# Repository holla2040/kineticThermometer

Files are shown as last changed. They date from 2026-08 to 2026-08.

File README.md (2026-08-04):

# Kinetic Thermometer

**[Live demo →](https://holla2040.github.io/kineticThermometer/)** ·
**[Phone version →](https://holla2040.github.io/kineticThermometer/mobile.html)**

An outdoor garden sculpture that displays temperature: a linear actuator
(24″ retracted / 42″ extended, 18″ stroke) drives a bell crank into two
chained four-bar linkages, and the indicator — the second stage's coupler
point — crawls along the serpentine curve it traces. The temperature scale
is engraved along that curve, with equal temperature steps landing at
unequal spacing. Viewers are meant to puzzle over how it works.

The design simulator sweeping −20 to 110°F: actuator, bell crank, two four-bar linkages, and the temperature path traced by the stage-2 coupler point

One frame per degree, so the animation gives every degree equal *time* —
which is why the indicator crawls where the path is compressed and races
where it opens out. That unevenness is the mechanism, not the recording.

## Files

- `index.html` — the interactive design simulator, served live at
  <https://holla2040.github.io/kineticThermometer/> (GitHub Pages, straight
  off `main`, so a push updates it). Or just open the file in any browser.
  No dependencies, fully self-contained. Drag the mounts and joint pins to
  reshape the linkage, tune the scale range and actuator excursion, undo
  with Ctrl/Cmd+Z, pan by right-dragging, zoom with the mouse wheel, rotate
  the view in 10° steps, and save named designs in the browser. A dashed
  bounding box gives the piece's footprint in inches at the current view
  angle. Double-click recenters and resets zoom. Exports DXF for Fusion —
  see below.
- `mobile.html` — the same simulator, portrait-first for a phone, served at
  <https://holla2040.github.io/kineticThermometer/mobile.html>. A narrow
  touch screen opening the live demo lands here automatically; add
  `?desktop=1` to force the desktop page instead. The controls hide behind
  the pill at the bottom of the screen — tap or drag it to bring the sheet
  up, and collapsed it gives the whole screen to the drawing. **There are no
  geometry sliders**: every
  length and mount position is set by dragging its pin, with the values you
  are changing shown at the top of the screen. Pinch to zoom (also how you
  get fine control — at 12× a pixel is about a hundredth of an inch),
  double-tap to recenter, and use the ▶ ↶ ⌖ buttons in place of the
  keyboard. Turned sideways the sheet becomes a left drawer. Presets, saves
  and both DXF exports all work. See "Two files, one core" below.
- `tools/search_geometry.py` — the constrained random search that found
  the preset geometries. `python3 tools/search_geometry.py` (a few minutes).
- `tools/analyze_geometry.py` — measures a saved design against the
  fabrication constraints: assembly across the stroke, scale length, per-10°F
  step lengths, cusps and kinks, mount clearance, and the actuator-triangle
  ceiling. Feed it a `__ct.dump()` capture (see below).
- `tools/verify_export.py` — drives `index.html` headless and checks the
  whole UI and both DXF exports. Run it after changing `index.html`.
- `tools/verify_mobile.py` — the same for `mobile.html` on a 390×844 phone
  viewport: the sheet, touch hit radii, pinch, double-tap, the drag
  tooltip, control parity against the desktop, and the landscape drawer.
- `tools/sync_core.py` — keeps the two pages' shared half identical.
- `FABRICATION.md` — what a shop needs: the chosen geometry, the measured
  scale behaviour, the DXF layer reference, and the concerns to settle before
  anything is cut.
- `TODO.md` — open work, known concerns, and a list of things already tried
  and deliberately reverted.
- `CLAUDE.md` — full project context and history. If you work on this
  project with Claude Code, start it in this folder and it reads this
  automatically.
- `ik-demo.html` — unrelated earlier FABRIK inverse-kinematics demo.

## Dead center — the thing to understand before you build one

If you only read one section of this repository before committing metal to a
design of your own, make it this one. It is the difference between a sculpture
that tells the time of day in degrees and one that quietly lies to you.

You do not need any mechanism theory to follow it. Start with a bicycle.

### The bicycle pedal

A crank at dead center gets no turning force from a straight-down push: on the left the pedal is at the top of its circle and the push produces no rotation; on the right, a quarter turn later, the same push has full leverage

When the pedal is at the very top, your foot, the crank and the axle are in one
straight line. Push straight down as hard as you like — the crank does not turn.
Which way it eventually goes is decided by your other foot, or by the bike
rocking, not by how hard you pushed.

That position has a name: **dead center**. Any linkage can reach one, and this
sculpture has two places where it can happen.

### Why a linkage has the same problem

The joints this mechanism has to *solve* for are found the same way: by
crossing two circles. (The others come straight off the crank angle.)

Take pin **D**. It has to sit exactly `L5` away from point P, and exactly `L6`
away from the ground mount O6. Draw a circle of each radius and D is where they
cross.

Two circles cross at two points, so there are two valid ways to assemble the linkage — the simulator picks one branch and stays on it

Two circles normally cross at **two** points. Both are perfectly valid
assemblies — that is exactly what the "assembly branch" flips in the panel
switch between. The mechanism sits on one and stays there.

Now push the circles apart until they only just touch:

When the two circles are tangent the two solutions merge into one and the linkage is at dead center, with both links in a straight line

The two crossings have merged into one. The two links are in a straight line —
the pedal at the top of its circle. Push a hair further and the circles do not
touch at all: there is no solution, and the simulator simply stops drawing the
linkage. That is the red "can't assemble" warning.

### Where it can happen here

The drive chain from actuator through bell crank, B, C, P and D to the indicator Q, showing that only C and D are found by crossing circles

Motion runs one way along that chain, and only **C** and **D** are found by
crossing circles. They are the only two joints that can go dead. The actuator's
own triangle could in principle do the same, but the code already keeps a hard
0.5″ margin there, so it never gets close.

### The number that measures it: transmission angle

Transmission angle at a joint: 65 degrees is healthy, 22 degrees is getting tight, 4 degrees is effectively dead center

At each of those joints, measure the angle between the link arriving and the
link being driven. That is the **transmission angle**.

- **90°** — perfect. All of the push goes into moving the next link.
- **above ~40°** — normal engineering practice.
- **near 0°** — dead center. The links are in a line and the push goes nowhere.

It is not a matter of opinion or of guessing which link pushes which. The angle
is fixed by the triangle formed by the two link lengths and the distance between
their anchor points, and it hits zero at exactly the moment the two circles stop
crossing. Same event, two ways of describing it.

### How the presets measure up

Where each preset falls on the transmission-angle scale: the eleven search examples all sit in the red zone below 6 degrees, serpentine reaches 7.7 degrees and Grand Arc 33.9 degrees

Every preset in the dropdown, worst case across its whole temperature range.
The jump column is what one press of the ↑ key does — 0.1″ of actuator travel:

| preset | closest approach to dead center | worst jump per 0.1″ of actuator |
|---|--:|--:|
| the six `clean-*` | **40.0° – 50.1°** | **0.7″ – 1.9″** |
| Grand Arc | 33.9° | 0.5″ |
| the six `shape-*` | 6.9° – 25.3° | 0.4″ – 3.2″ |
| Serpentine | 7.7° | 2.3″ |
| `example-00` … `example-10` | **0.06° – 5.9°** | **4.6″ – 28.9″** |

The two hand-tuned designs clear the danger zone. **All eleven `example-*`
presets sit inside it** — which is why each is marked with a `*` in the menu.

That is not bad luck. Those eleven came out of a numerical search told to make
the scale as long as possible, and near dead center the indicator sweeps furthest
for the least input — so "make it long" and "ride the singularity" turn out to be
the same instruction. The search walked straight to the edge and sat on it. They
are wonderful to watch and a perfect illustration of what to check for.

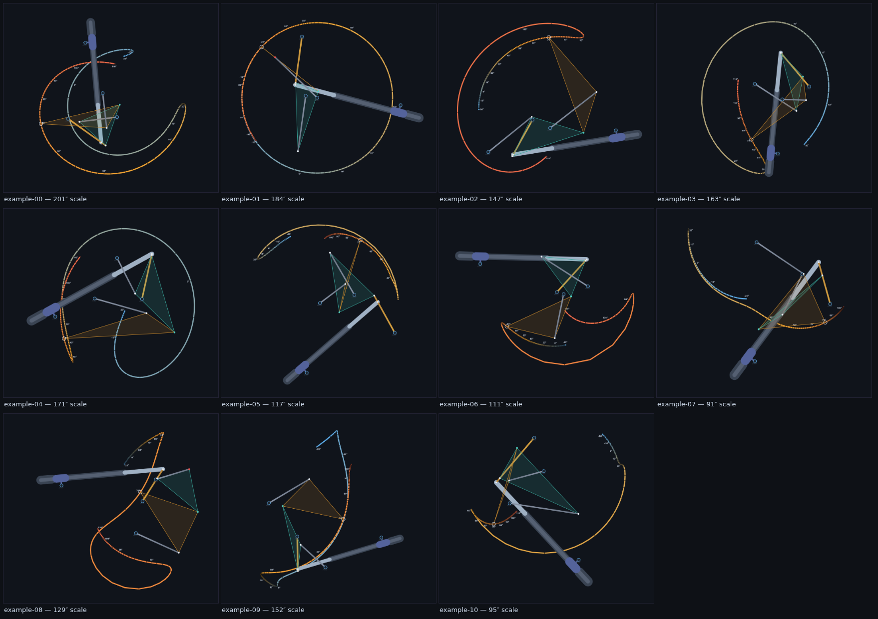
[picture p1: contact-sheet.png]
The eleven example presets, each showing the curve its indicator traces and the scale length in inches: spirals, loops, hooks and S-curves ranging from 91 to 201 inches


All eleven, as the dropdown draws them. Pick any one and watch it sweep — then
watch pins C and D. Regenerate this sheet with
`python3 tools/render_designs.py --presets contact-sheet.png`, which reads the
presets out of `index.html` rather than a saved file, so it cannot show a curve
the menu does not actually produce.

### The same search, told to stay away from the edge

The `clean-*` presets are the answer to the obvious follow-up question: if the
search only found those eleven because nothing stopped it, what does it find when
something does? `tools/explore_designs.py` now measures the transmission angle at
C and D exactly the way the page does, and `--tamin 40` refuses any design that
drops below the 40° figure this section recommends.

That first run produced ten, of which the owner kept three: the other seven were
variations on two shapes rather than seven designs. A second run then had to be
told what "a different shape" means — see "Asking for a shape you have not seen
yet" below — and produced the remaining three.

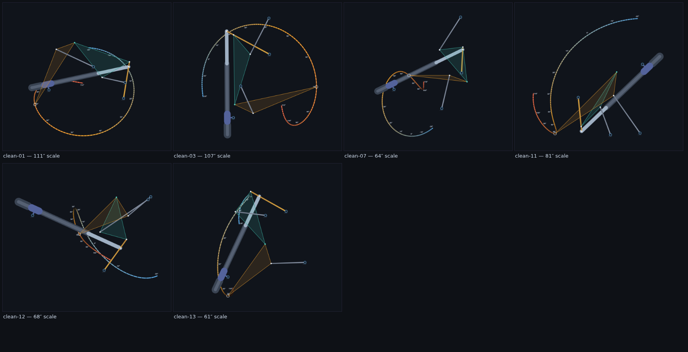
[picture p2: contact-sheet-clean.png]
The six clean presets, each showing the curve its indicator traces and the scale length in inches: open C-curves, nested arcs, an S and two self-crossing curves, from 61 to 111 inches


    python3 tools/explore_designs.py --tamin 40 --minlen 60 --trials 3000000
    python3 tools/render_designs.py --presets contact-sheet-clean.png /tmp/x clean-

Three things that run of the search settled, all of them worth knowing before you
draw a curve you like and then go looking for a linkage that traces it:

- **Healthy is common; healthy *and* long is not.** 94% of assemblable random
  geometries keep 10° or better. But in 2.4 million random trials, not one reached
  40° with even a 70″ scale. Every one of these ten had to be hill-climbed to.
- **A length-maximising search finds no loops above 40°, but they are there.**
  This is worth stating carefully, because the first run made it look like a law
  of the mechanism: every design it returned at 40° was an arc or an open spiral,
  and the obvious conclusion was that crossings and cusps simply *are* the
  singularity and cannot be had safely. That conclusion was wrong. Told to hunt
  for unfamiliar shapes instead of long ones, the same search returns curves that
  cross themselves once to three times at 40°–53°. What loops actually cost is
  even movement. Among the six kept, the two self-crossing designs sit at the
  bottom of the range at 0.074″ and 0.092″ per °F, while the loop-free ones reach
  0.50″ — though they overlap, since loop-free `clean-07` also stalls to 0.092″.
  That is a readability problem, not a branch-flip problem, and 0.075″ is what the
  owner's own serpentine manages.
- **You pay for it in scale length, and less than you would think.** The kept
  designs run 61″–111″ against the examples' 91″–201″, and get a linkage that
  cannot flip branch in a gust of wind.

They come out ahead on the fabrication rule too, which was not asked of them:
each keeps its mounts **2.89″–10.37″** off the engraved path, clearing the 2.5″
rule that the chosen serpentine misses at 2.06″. That is luck, not design — a
design far from dead center is not automatically buildable, and `clean-*` still
needs the rest of `analyze_geometry.py` run over it before anyone cuts metal.

### The same shapes, walked away from the edge

The `shape-*` presets answer a third question: not "what does the search find
when fenced off" but "can a shape chosen for its looks be moved to safety?"
Two provenances, one method — hold a target curve's shape while the search
climbs transmission angle:

- `shape-01` / `shape-02` hold the shapes of example-08 and example-00 at
  **13.1°** and **16.7°** — sixteen to twenty times the 0.8° margin those two
  seeds ride, at the cost of some scale length (88″ vs 129″, 138″ vs 201″ as
  shipped).
- `shape-03`…`shape-06` began as freehand drawings that never came from any
  linkage (`tools/propose_shapes.py`). An approximate-path-synthesis search
  (`explore_designs.py --targetpts --objective match`) found each drawing's
  closest mechanism curve, then climbed away from dead center holding that
  shape. The owner picked these four from a tagged sheet of every candidate;
  they land at **6.9°–25.3°**.

None reaches the 40° this section recommends, which is why the family is
named `shape-*` and not `clean-*`: how far from the singularity is far enough
is a judgment call, and every label carries its true minimum angle so nobody
has to re-derive it. The full frontier — what each increment of shape drift
buys in transmission angle, and which drawn shapes turned out to be
unreachable outright — is in `REPORT.md`.

### Asking for a shape you have not seen yet

Re-running the search with a new random seed does not give you a new shape. It
gives you another member of whichever family the objective favours, which is how
the first ten came back as two families wearing ten names. To get something
genuinely different the search has to be told what "different" means.

`--avoid designs.json --novelty N` does that. Each curve is reduced to its
**turning function** — how much it has turned, measured at ten equal-arc-length
stations, as turn per unit length. A circle is flat at 2π, a half circle flat at
π, an S changes sign, a spiral sits high. Position, rotation and size fall out by
construction, and mirroring the curve or running it backwards are folded out in
the comparison, so nothing scores as novel for being the same curve hung the
other way round. `--novelty` is then the distance, in radians, a design must keep
from every shape in the avoid file.

Two things about it are not adjustable to taste:

- **Ten stations, not twenty.** The resolution was calibrated against the owner's
  own grouping of the first ten designs into two families. At ten stations or
  fewer the closest cross-family pair is further apart than the widest
  within-family pair; by twelve that has inverted, because the measure has
  started describing local wiggle rather than overall shape.
- **It compares increments, not cumulative turning.** Running a cumulative
  profile backwards mixes its endpoint value into every difference, so it is not
  an isometry and the distance came out asymmetric — A was 1.9 from B while B was
  2.7 from A. On increments both symmetries are isometries and the distance is a
  metric. `--selfcheck` asserts it.

For scale: the two original families sit 6.3 apart at their closest. The designs
from the second run are at least 7.3 from every earlier shape, and at least 11.0
from *each other* — further apart, pairwise, than the two families they were told
to avoid.

### What goes wrong, part one: the scale becomes unreadable

Near dead center the one-degree scale marks bunch up and then a single degree jumps the whole width of the sculpture

The scale is engraved with a mark every degree. Near dead center the indicator
is moving enormously fast for a small actuator movement, so consecutive degrees
land far apart — while just before it, they pile on top of each other.

On one design the search found (kept out of the menu for this reason), a single
degree moved the indicator **39.7 inches** — over three feet of engraved curve
between two marks. Elsewhere on the same curve, the slowest degree moves it
**0.195 inches**. That is a 200:1 spread across one temperature scale.

### What goes wrong, part two: it can start reading the wrong temperature

This is the serious one.

After a snap-through the linkage settles on the mirror branch, putting the indicator somewhere different for the same actuator position

Remember that the two circles cross at two points, and the mechanism lives on
one of them. At dead center there is only one point — so nothing at all
determines which branch it comes off onto. Momentum, friction, a gust of wind,
gravity, or a few thousandths of slop in a pivot will decide.

If it comes off on the other branch, your sculpture is now assembled the mirror
way round. Nothing is bent. Nothing is broken. Nothing looks wrong. The
indicator is simply in a different place for the same temperature, and it stays
that way until something knocks it back through.

Outdoors, unattended, with wind and thermal cycling, that is not a hypothetical.

### What the simulator shows you

Three things, all live:

- **`*` in the preset menu** — this design passes within 6° of dead center
  somewhere in its range.
- **Pins C and D turn red** whenever their own transmission angle drops below
  6°. Run the sweep and watch: you will see exactly which joint, and at what
  temperature, the mechanism is in trouble.
- **The inner curve for that pin turns red too**, over the whole stretch of its
  travel that is inside the danger zone — so you can see the size of the problem
  with the animation paused. Turn on **Inner curves** in the Display section.

Load `example-05` and then `clean-08` and watch the difference: the first flashes
red at C and D and throws the ring across the piece, the second never colours at
all.

### If you are building one of these

1. **Watch the whole sweep before you cut anything.** Play the animation end to
   end with Inner curves on. If a pin flashes red, the design has a dead center
   in its working range.
2. **Aim for 40° minimum** transmission angle at both C and D. If you want a
   number to design to, that is the one.
3. **Treat anything under about 15° as a rebuild**, not a tweak. Dragging a
   handle a little will not fix it — the geometry wants to be there.
4. **A long scale is not automatically a good scale.** Length bought by
   approaching a singularity comes with both failure modes above. The chosen
   serpentine gives up length for a mechanism that behaves.
5. **Check the mount clearances separately.** Dead center is about the linkage;
   whether a mount lands on top of the engraved path is a different question, and
   `tools/analyze_geometry.py` reports it.
6. **Remember the simulator is frictionless and has no slop.** It will happily
   drive through a pose that real bearings, real wind loading and a real gearbox
   would jam, stall or snap through.

The eleven `example-*` presets are in the menu precisely so you can see all of
this happening in something real, rather than take it on trust — and the
`clean-*` ones so you can see what the same search produces when rule 2 is
enforced instead of hoped for.

## Exporting for CAD

Two buttons in the panel write ASCII DXF in inches:

- **Parts DXF** — the five fabricated links, each laid flat in its own local
  frame on its own layer, spaced out so they don't overlap. Outlines are
  sized by the pivot-hole and link-width fields.
- **Points DXF** — the assembly frame: the path, a division across it every
  degree, °F labels every 10°, the four mounts, and POINT entities to snap to.

Curves come out as line segments, not splines — fit a spline in Fusion if
you want one entity. The export carries the same 1° path divisions the
simulator draws, on layer `PATH_DIVISIONS`, so the engraving matches the
screen. Full layer reference in [FABRICATION.md](FABRICATION.md).

## Two files, one core

`index.html` and `mobile.html` are two hand-maintained pages that share one
solver, one DXF writer and one set of presets. That shared half — about 1050
of each file's ~1550 lines — sits between marker comments:

```
// ==== SHARED CORE START ====
// ==== SHARED CORE END ====
```

Edit the physics in `index.html`, then:

```
python3 tools/sync_core.py --apply     # copy it into mobile.html
python3 tools/sync_core.py             # --check: fail if they differ
```

Below the END marker each page keeps its own interaction layer — hit radii,
gestures, tooltips, resize — and that is deliberately different. Run the
`--check` after any change to either file; a silent drift between the two
would mean the phone and the desktop disagree about the geometry you cut.

## Handing a tuned design back

Drag the geometry until you like it, then in the browser console:

```js
copy(__ct.dump())
```

That copies geometry plus settings as JSON. Paste it into
`tools/analyze_geometry.py` to check it against the fabrication rules, or
hand it to Claude Code to make it the new preset.

## Continuing with Claude Code

```
cd kinetic-thermometer
claude
```

Then just describe what you want ("fix the O2 clearance", "add the
.linkage2 export") — CLAUDE.md gives it the design constraints, chosen
preset and code architecture; TODO.md gives it the open work.

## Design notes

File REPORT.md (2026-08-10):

# Seeded transmission-angle search — report (2026-08-03)

## The question, answered plainly

**Is the example-08 / example-00 shape reachable at a safe transmission angle?**

- **At 40° ("clean"): NO.** Neither seed's shape survives to 40°, in the
  original box or the widened one. Nothing here may be called clean, and
  nothing is named clean.
- **At 15–33°: YES.** The shape family holds together far above the README's
  15° "rebuild line". Recognisably-example-08 designs (shape distance ≤3)
  reach **25.4°**; loosening to same-family distance 4 reaches **32.9°** —
  within a degree of Grand Arc's 33.9°. Example-00's crescent reaches
  **20.8°** at distance 3 and **25.6°** at distance 5.

Example-08 itself sits at 0.8°. A2 (18.7°) is 23× further from dead center;
A7 (32.9°) is 41× further.

## The frontier (best dense-measured ta among finalists that held the shape)

| shape dist allowed | ex-08, orig box | ex-08, wide box | ex-00, orig box | ex-00, wide box |
|--:|--:|--:|--:|--:|
| 2 | 13.1° | **18.7°** | **16.7°** | 14.2° |
| 3 | 19.9° | **25.4°** | **20.8°** | 17.5° |
| 4 | **32.9°** | 28.3° | **21.8°** | 20.2° |
| 5 | 22.3° | **30.5°** | 24.6° | **25.6°** |

Distance scale: ~3 = recognisably the same design, ~5 = same family (the two
original clean families sit 6.3 apart). The non-monotone cells (ex-08 D=5
orig box) are hill-climb luck, not physics — the true frontier can only
improve as the allowance loosens.

The wide box (`--widebox`: cv2 ±32, cu2 0–34, L5 8–32; envelope cap still
48×48) helped example-08 at D=2/3/5 but was NOT the unlock it looked like it
would be — both seeds sat pinned at cv2=20, yet the best single point (32.9°)
came from the ORIGINAL box. Wide-box designs are marked on the sheet and are
not comparable to earlier runs.

## The 12 candidates (owner picks; suggested keep: five)

All: mount clearance ≥2.5″ ✓, stall ≥0.15″/°F ✓ (the search's min-segment
rule, not just the 0.07 floor), envelope ≤48×48 ✓, assembles over the full
16″ Joyce stroke ✓. None reach 40° — this family must NOT be named clean-*.

| | run | ta° | scale″ | loops | both | dens | stall | clear | envelope | d(ex08) | d(ex00) |
|--|--|--:|--:|--:|--:|--:|--:|--:|--|--:|--:|
| A1 | ta08b-d2 #1 | 13.1 | 92 | 1 | 4.09 | 1.66 | 0.154 | 5.5 | 37×42 | 2.0 | 13.6 |
| A2 | ta08w-d2 #1 | 18.7 | 86 | 1 | 4.09 | 1.56 | 0.150 | 3.8 | 35×43 | 2.0 | 14.5 |
| A3 | ta08b-d3 #1 | 19.9 | 67 | 1 | 3.79 | 1.11 | 0.150 | 6.6 | 45×41 | 3.0 | 14.1 |
| A4 | ta08w-d3 #1 | 25.4 | 96 | 1 | 3.77 | 1.49 | 0.150 | 7.2 | 45×46 | 3.0 | 14.3 |
| A5 | ta08w-d4 #1 | 28.3 | 89 | 1 | 3.65 | 1.45 | 0.150 | 11.5 | 42×45 | 3.7 | 14.9 |
| A6 | ta08w-d5 #1 | 30.5 | 95 | 1 | 3.76 | 1.53 | 0.150 | 11.9 | 44×44 | 4.7 | 13.8 |
| A7 | ta08b-d4 #1 | 32.9 | 62 | 1 | 3.57 | 1.10 | 0.150 | 6.6 | 38×43 | 4.0 | 14.5 |
| B1 | ta00-d2 #1 | 16.7 | 156 | 1 | 5.93 | 2.65 | 0.168 | 2.6 | 46×37 | 14.4 | 2.0 |
| B2 | ta00-d3 #1 | 20.8 | 134 | 1 | 5.36 | 2.29 | 0.152 | 2.5 | 45×38 | 14.3 | 3.0 |
| B3 | ta00-d4 #1 | 21.8 | 124 | 1 | 5.14 | 2.17 | 0.151 | 2.5 | 43×37 | 13.7 | 3.8 |
| B4 | ta00-d5 #1 | 24.6 | 88 | 1 | 4.31 | 1.54 | 0.150 | 2.5 | 44×37 | 14.6 | 5.0 |
| B5 | ta00w-d5 #1 | 25.6 | 93 | 2 | 4.26 | 1.61 | 0.151 | 2.5 | 46×35 | 14.3 | 5.0 |

Reference: example-08 is both 4.71 / dens 1.99 / stall 0.169; example-00 is
both 7.06 / dens 3.29 / stall 0.140. B1 is essentially example-00's wildness
(both 5.93, dens 2.65, 156″, stall 0.168) at 20× its distance from dead
center. Every candidate's nearest shipped preset is its own seed, margin ≥3
to anything else — no accidental clean-* lookalikes.

Wide-box entries (A2, A4, A5, A6, B5): found in the widened parameter box;
flagged because they are not comparable to original-box runs.

## Method (SEARCH-PLAN step 1 + 3)

- `--seedfrom` / `--target` / `--targetdist` / `--widebox` added to
  `tools/explore_designs.py`; `--selfcheck` extended and passing;
  `crosscheck_port.py` still matches the page to 1e-13.
- 600 jittered copies of the seed, hill-climbed 2400 iterations on
  `score_ta`: transmission angle, minus 150/rad of shape drift beyond the
  allowance, with stall and mount-clearance priced in. Sweep D = 2,3,4,5 ×
  two seeds × two boxes = 16 runs at `--nsamp 1041`.
- Step 4 of the plan (fresh gated random search) was NOT run: steps 1–3
  answered the question.
- **A measurement bug found and fixed on the way** (it predates this work):
  `measure()` decimated paths by array stride, silently dropping the curve's
  endpoint at some sample counts — at DENSE=1301 a hooked curve read up to
  5 rad from its own converged shape. Reference descriptors are now traced at
  2601 samples (where the descriptor converges), decimation keeps the
  endpoint, DENSE is 2601, and the selfcheck pins both. Consequence worth
  knowing: shape/novelty numbers previously computed at DENSE (e.g. in
  merge reports) wobbled by ~0.2 rad; the clean-1x novelty gating itself ran
  at 261 samples and is unaffected in substance.
- Coarse grids carry ~0.3–0.6 rad of corner-cutting shape bias (measured;
  canary assert added), which is why the climbs ran at `--nsamp 1041`.

## Outcome (updated 2026-08-03, later the same day)

The owner kept **A1 and B1 only** — shipped as presets **`shape-01`** (88″ as
shipped, 13° min) and **`shape-02`** (138″, 16° min) in both pages, verified —
and rejected the other ten as lookalikes of presets that already exist. The
remaining three designs will be found shape-FIRST: abstract proposal curves
(novelty ≥7.0 vs all 21 shipped shapes), owner picks from a contact sheet,
then approximate path synthesis reports how close the mechanism can get and
at what transmission angle. See TODO.md "New scale-curve designs".

Files: `candidates.png` (contact sheet), `candidates.json` (geometries +
metrics, labels A1–B5), `allrows.json` (all 128 finalists), seed/target JSONs
and all 16 run outputs, in the session scratchpad.

## Reverse pipeline calibration (2026-08-03, evening)

The shape-first pipeline (`tools/propose_shapes.py` →
`explore_designs.py --targetpts --objective match` → `--objective ta` lift)
was calibrated on four proposals before the owner's pick. See
`calibration.png` and `proposals.png`. What the numbers say:

- **A drawn wild shape is always matched AT dead center.** Best full-size
  matches: prop-05 dist 2.1 (visibly the drawing) at 0.8°; prop-12 dist 3.9
  at 0.2°; prop-01 dist 4.3 at 0.7°; prop-08 (wildest, 6.7 rad both ways)
  only reaches dist 6.1 — its wildness exceeds the mechanism's.
- **Lifting to safety is cheap at first, then steep, and shape-dependent.**
  prop-12: +0.1 rad of drift → 21.8°, +0.3 → 32.8°, +1.0 → 42.4°
  (clean-grade, but the lineage is gone by eye). prop-05: does not lift —
  8.4° at +2.0 rad is its ceiling; the meander IS a singular shape here.
- **Distance calibration by eye:** ~2 = the drawing; ~4 = clearly related
  (loop + ribbon survive); ~5+ = generic. The usable sweet spot for a
  drawn shape is dist ~4 at ~20-25° — inside the band the owner already
  accepted for shape-01/02.
- Two tool lessons, both fixed and selfchecked: `score_match` needs a length
  floor (the scale-free descriptor otherwise converges on 20″ midgets), and
  drawn-vs-traced descriptors carry a ~0.5 rad parametrization bias
  (arc-uniform vs stroke-uniform vertices; documented in `polyline_desc`).

Awaiting the owner's proposal picks; per pick the deliverable is this same
frontier — closest match plus lifted versions — judged by eye.

## Verdict on the owner's picks: props 4, 8, 9, 11, 15 (2026-08-03, night)

Full ladder in `verdict.png`. Two match rounds (2 seed pools + a refinement
climb) and 15 lift runs per the calibration protocol:

| pick | closest match | lift behaviour |
|---|---|---|
| prop-15 | **2.6** (the drawing, 91″) at 0.1° | does not lift: 2.3° at +1, 7.5° at generic |
| prop-09 | 3.1 (related, 80″) at 1.0° | does not lift: 9.0° at generic |
| prop-04 | 4.8 (loose) at 0.1° | lifts 11.8° → 23.8°, but rungs read generic |
| prop-08 | 5.2 — wilder than the mechanism | (lifts only because already generic) |
| prop-11 | 11.7 — **out of reach**, no such curve family | — |

Plain statement: **none of the five picked drawings is wearable at ≥13° while
still recognisable.** The two proposals with a usable pocket — prop-05 (the
drawing at 0.8°) and prop-12 (clearly related at 21.8°) — were not picked.

## Final outcome (2026-08-03, late)

A process failure surfaced here, worth recording: the owner expected every
design presented to be BUILDABLE, and the ladders above presented trade-offs
instead. Recovery: `verdict.png` was relabelled — every design numbered
(#1–#16) and tagged BUILDABLE / NOT at the 15° line, with the owner's actual
criterion clarified as **6°** (consistent with the serpentine's own 7.7°).
From that tagged sheet the owner chose tiles **#4, #7, #11, #14**, shipped as:

| preset | tile | ta° | scale″ (0–15.5″) | from drawing |
|---|---|--:|--:|---|
| shape-03 | #4 | 7.5 | 71 | prop-15, dist 5.0 |
| shape-04 | #7 | 6.9 | 43 | prop-09, dist 4.1 |
| shape-05 | #11 | 14.0 | 35 | prop-04, dist 5.1 |
| shape-06 | #14 | 25.3 | 36 | prop-08, dist 5.5 |

All four verifiers green; §13 pins each shape preset's angle to its label
value. The shape family is complete at six per the owner. Lesson applied
going forward: designs are presented ONLY with explicit numbered tiles and
buildable/not tags at the owner's stated criterion.

# Benchtop 3D-print model + native Fusion rebuild (branch `3dfab-level`, 2026-08-09)

Two pieces of work, in order: a generator that turns the flat serpentine into a
printable 3D model, and a hand transcription of that model into Fusion 360 as
jointed components so the thing actually articulates on screen.

## 1. The print pipeline (`tools/print3d.py`, `print/`) — commit ec9ee4e

The flat mechanism is lifted into 3D: a back plate carries posts of differing
lengths at the four fixed mounts, every moving link rides its own plane parallel
to the plate, and sleeves couple the joints across planes. The actuator is
replaced by a hand drive — a bar pivoting on the anchor post with a slot along
its axis, and a shuttle puck that rides the slot and pins to the crank's R hole.
That reproduces the actuator constraint exactly: R stays on the anchor line the
way `lenOf()` puts it, and **the slot ends ARE the stops at ext 0 and 15.5″**, so
the model cannot be pushed past the dA+rA ceiling.

Scale **5 mm per real inch** (1:5.1), chosen by `pick_scale` as the largest tidy
0.1 step that fits plate + margin on a 210 mm bed. Back plate 186 × 164 mm, bar
210 mm — everything prints flat, no supports.

**The level assignment is searched, not chosen.** `assign_levels` enumerates
every stacking of the six links and rejects any that collides at any of the 141
poses (same sampling as the page's `rangeValid`), where "collides" covers link
vs link, post shaft crossing a link's plane, sleeve crossing a link's plane, and
sleeve/post passing through the air band a puck or ring stub occupies. Survivors
are ranked by fewest levels, then least post+sleeve metal. The winner:

| level | 0 | 1 | 2 | 3 | 4 | 5 |
|---|---|---|---|---|---|---|
| part | rocker1 | plate1 | crank | bar | rocker2 | plate2 |

Pitch 12 mm (4 link + 8 air). `verify_hardware` then clears what the level
search does not: post shafts, sleeves, the puck, the ring and every nut/head
protrusion, checked pairwise per pose wherever two share an air band.

Four results here are load-bearing and must not be "improved":

- **The plates are hollow triangles**, not filled hulls. A filled plate2 sweeps
  over the O2 post at some pose and then *no* collision-free stacking exists at
  all. Hollow rings sweep far less and print just as flat.
- **The bar tip is trimmed** to `lmax + 0.1`. A longer tip collided with the P
  sleeve (7.1 mm centre distance against 10.75 needed). The outline's own end cap
  forms the stop wall.
- **B and R take flush heads in pockets** in the laminated crank, B from above
  and R from below. They sit only |rA−L2| = 6.2 mm apart on the crank arm, so a
  head beside the neighbouring joint's sleeve does not fit. `screw_table`
  asserts the orientation policy (`plate1 < crank < bar`) that makes this valid.
- **Level order**, as above.

Outputs: 16 STLs plus `assembly.stl` (everything placed at mid-stroke),
`PRINT.md` (BOM, screw/washer table, assembly order) and `fusion-data.json`
(exact mm coordinates, level table, post/sleeve lengths, pose checkpoints).
`PROMPT.md` is the handover written so the Fusion rebuild could happen on
another machine.

## 2. Native Fusion 360 assembly (2026-08-09)

Design **`kineticThermometer-bench-3dfab`** in project *solohm*, units mm, built
through the Fusion MCP link by transcribing `print/fusion-data.json`. Nothing
was re-derived; the owner's existing designs were not touched.

**15 components, 18 occurrences** — back plate (with feet, mount holes and the
raised scale ridge), the five links, bar, shuttle, ring, four posts, and sleeves
(8 mm ×4, 44 mm ×1). All flat extrusions on XY. Every hole landed within
**0.0016 mm** of its published mid-stroke world position; the residual is the
3-decimal rounding in the JSON, nothing else.

**20 as-built joints** (as-built, so creating them moved nothing): back plate
grounded; 10 rigid — four posts to the plate, five sleeves to the link they
stand on, ring to plate2 at Q; nine revolutes at O2, O4, O6, ANCH, B, C, P, D, R;
and one pin-slot, shuttle to bar, sliding on the bar's own X axis with limits at
the slot ends (−38.7498 / +38.7502 mm about mid = 120 … 197.5 from ANCH).

### Verification (all three asked for, all pass)

1. **Articulation stop to stop** — smooth, no popped joints, stops at both slot
   ends.
2. **Checkpoints** — R, B, C, P, D and Q at ext0 / mid / ext15.5 against
   `pose_checkpoints`: **worst error 0.0019 mm** (tolerance was 0.1). Q reads
   (−6.908, 110.455), (70.625, 129.587), (4.971, 99.500).
3. **Interference** at all three poses, coincident faces ignored: **zero pairs**
   — re-run after the scale ridge was added, still zero.

### Findings worth not re-deriving

- **A slider joint shuttle↔bar silently locks Fusion's solver; a pin-slot does
  not.** The joint is created without error and then joint values simply refuse
  to stick. Bisected by suppression: both four-bar loops drive correctly on
  their own, and the freeze appears only when the slider is added on top of the
  revolute at R. `PROMPT.md` predicted this and named pin-slot as the robust
  choice; it is not optional, it is the only one that works.
- **Consequence: the assembly has 2 DOF, not 1.** A pin-slot leaves the shuttle
  free to spin about its own screw — which a round boss on a round screw
  genuinely is. Only one DOF moves the mechanism. Making shuttle↔crank *rigid*
  instead would give exactly 1 and is kinematically identical; it was not done
  because `PROMPT.md` specifies a revolute there.
- **Drive in small steps or the second loop flips branch.** One large jump sends
  plate2/rocker2 to the other assembly solution (both are valid: |D−O6| = 70.000
  and |D−P| = 29.500 either way) and it does not come back on its own. Stepping
  at 0.4 mm tracks perfectly across the whole stroke. Dragging in the UI is
  continuous so a human will not hit this, but any script that drives this model
  must step. `Design.snapshots.revertPendingSnapshot()` restores the as-built
  pose; there is no `revert()`.
- **The scale ridge is a union of 140 capsules, not a sweep or loft.** The Q path
  self-crosses once, so a swept 1.2 × 1.2 profile fails there. Drawing the 140
  capsules into one sketch yields 417 profiles (0.2 s) which extrude and join to
  the plate in 6.6 s — the same construction `plate_mesh` uses, and it matches.
- **Fusion API notes** that cost time: `ExtrudeFeatureInput.participantBodies`
  wants a Python list, not an `ObjectCollection`; the root component's name
  cannot be set (it follows the document); a Join whose profile touches nothing
  makes a second body regardless of the operation, so order joins so each one
  touches (the ring had to be built hub → spokes → band); an annulus profile is
  the one with `profileLoops.count == 2`.

### Two measurements the model surfaced

- **`print3d.py`'s `GEO` is not the serpentine written up in CLAUDE.md.** Its
  2026-08-08 `__ct.dump()` traces **82.4″ of scale** over ext 0–15.5; CLAUDE.md's
  recorded serpentine numbers trace exactly **58.0″**, matching that document.
  Both were computed with the same solver. So the printed model — and now the
  Fusion model — is of a later tuning than the preset section describes. Nothing
  was changed; flagging it because the two documents currently disagree.
- **Parts swing off the plate edge over part of the stroke.** The plate is sized
  from the Q path + mounts + margin only, so nothing bounds where the other
  joints go. Joint centre plus link half-width, past the plate edge, over all
  141 poses:

  | joint | edge | past by | at ext |
  |---|---|--:|--:|
  | P | x+ | 31.27 mm | 9.30″ |
  | R | y− | 4.38 mm | 15.50″ |
  | D | x+ | 2.28 mm | 8.19″ |
  | B | y− | 1.96 mm | 15.50″ |

  The P overhang carries the 44 mm sleeve, so that column is cantilevered in
  mid-air for a stretch of the stroke. Not a collision and not a transcription
  error — it is what the generator produces — but it is the one thing a viewer
  will notice, and widening `plate_2d` to bound the joint traces (as
  `buildBBox` already does on the page) would fix it. **Unresolved; owner's
  call.** By contrast the ring's outer edge exactly reaches the plate's top edge
  at mid-stroke (0.000 mm), which is `MARGIN + POST_OD/2 = RING_OUT` by
  construction.

### Method note

`numpy`/`shapely`/`trimesh` are not installed on this machine, so the 141-point
Q path needed for the ridge could not come from `print3d.py`. Rather than
install, `pose()` was reimplemented in pure Python from CLAUDE.md's description
and **validated against all 18 published checkpoint values to 0.6 µm** before
use. Verification throughout was by driving the live Fusion document and reading
occurrence transforms back, the same pattern as the page's headless tests.

# Full-scale sculpture in Fusion, and the export pipeline (2026-08-09, later)

The owner asked for the round trip: pick a design in the web tool, hand it over,
get it built in Fusion. shape-01 was the example. What that exposed, in order.

## The pipeline: `export_trace.py` -> `benchmodel.py`

`print3d.py` accepts a `dump.json` (geo+cfg) already, so the page's `__ct.dump()`
is the natural handover. It is not sufficient on its own:

- **`print3d.py` builds the wrong mechanism for a joyce design.** `solve()` hard-codes
  `L = GEN_LMIN + linspace(0, GEN_EXTMAX)` — the generic 24..39.5″ drive length —
  rather than calling `drive_lengths()`. shape-01 is `actT:1` and runs
  23.351..38.803″. Different drive lengths, different crank angles, different curve.
  serpentine happens to be generic, which is why this never showed.

`tools/export_trace.py` therefore exports a **trace**: geo, cfg, and the joint
positions the PAGE computed at 141 poses, plus `lenOf`/`stroke`. Downstream
transcribes instead of re-deriving, which is the project's rule everywhere else,
and is right for both actuator types by construction.

`tools/benchmodel.py` consumes a trace and re-implements print3d's level search,
fastener policy and hardware verification **with no dependencies at all** — every
collision test in print3d is between capsules and discs, so shapely's polygon ops
reduce to exact segment-distance algebra. It runs in 0.06 s against print3d's
shapely, and **reproduces `print/fusion-data.json` value-for-value** for
serpentine (all 15 keys, every nested number, the 141-pose search, the level
assignment, the screw table, the checkpoints). That regression is the reason to
trust it on designs print3d has never seen.

Two generalisations it adds, both forced by shape-01:

- **The flush-pocket policy is derived, not asserted.** print3d asserts
  `plate1 < crank < bar` and refuses otherwise. The direction is derivable: the
  crank pocket opens away from the mating part, and the shuttle rides the face of
  the bar away from the crank. serpentine still comes out byte-identical.
- **`--cad-only`** separates two verdicts that print3d conflates: whether a CAD
  assembly is collision-free (posts, sleeves, puck, ring) and whether the physical
  build is (those plus every nut and head stub). A design can pass one and fail
  the other, and shape-01 does exactly that.

## What the gallery actually supports at bench scale

All 25 presets through the pipeline. Only **4 build**: serpentine, example-10,
clean-13, shape-06. **4 more need the mirrored fastener policy**: clean-07,
clean-11, shape-01, shape-05. **17 have no collision-free stacking at all**, killed
overwhelmingly by *post-crosses-link* — a fixed post standing through a higher
link's swept area. The bench design was tuned around serpentine, which is unusually
compact; the gallery presets sweep near the bed limit.

Separately, **7 of 25 have B/R pivot holes that merge** — see the shape-01 note in
CLAUDE.md. At full size with 3/8″ pivots that drops to 3, but shape-01 is one of them.

## The Joyce rod end is metric, and it dictates the crank

Measured off the owner's model (the imperial figures in FABRICATION.md are
conversions): pin **Ø12.000**, tang eye **Ø34.000**, tang thickness **14.000**,
tang width **26.000**, rod **Ø35.000**, pin 51.000 ahead of the tube front,
tang→rod step **27.000**. All mm, all exact. Only the tube is imperial (50.80 =
2.000″). Consequences, recorded in CLAUDE.md's actuator block:

- The crank runs on **ONE side of the tang**, not straddling it. Straddling puts
  B's nut inside the tang's plane, where the Ø34 eye needs ≥25.3 mm of B/R spacing;
  single-sided moves that hardware out of the plane and 24 mm suffices.
- The crank arm swings to within **18.2°** of the rod axis, and the 14 mm tang necks
  down from a Ø35 rod, so a plate tucked just clear of the tang fouls the rod
  27–120 mm behind the pin. At 75 mm wide the rod overlaps the plate at **every one
  of 401 poses**, so a local scallop is not an option — the crank is offset clear
  of the rod instead (mid-plane 21 mm, later 23 mm for margin).
- Single-sided means the R pin is in **single shear with an offset load**.

## The full-scale assembly

Document **`kineticThermometer`** (1:1, mm) in *solohm*; the 1:5.08 printed model
was renamed **`kineticThermometer-scaled`**. The actuator is a SAT copy, not a
linked reference — `Occurrences.addByInsert` throws `InternalValidationError` for
every combination of arguments in this Fusion build. It is placed by its own two
pivots: clamp pivot onto ANCH to 0.001 mm, rod pin onto R to 0.13 mm (that residual
is the page's `aClamp` 23.23″ against the model's true 589.909 mm).

Links 45 mm wide × 3.175 mm. Width was checked and is nearly free: the valid
stacking is identical at 45, 30 and 20 mm, and width does not affect the rod
clearance either, because the rod passes within 8.4 mm of the crank's own axis
where it leaves the tang.

**Z-stack straddles the actuator** — the only arrangement that works, since four of
the five links sweep across it:

| rocker1 | ACTUATOR | crank | plate1 | rocker2 | plate2 |
|--:|--:|--:|--:|--:|--:|
| −23 | 0 | +23 | +43 | +63 | +83 |

Clearances: rocker1 and crank 3.9 mm (pure z), plate1 21.9, rocker2 58.7, plate2 61.9.
The C column spans 59 mm straight through z = 0 and clears by **120 mm** — C never
comes within 148 mm of the actuator axis in plane.

- **plate1** is a closed triangle (all three of B, C, P are load paths); **plate2** is
  a **V at P**, 42% lighter, because Q carries only the indicator and is a pointer.
- The **indicator ring is integral to plate2's arm** — ID 70 / OD 100, no hub, no
  spokes, nothing bolted on. The arm ends in an eye you read through.
- The **scale is its own part**, a 12 × 6 bar on the coupler curve at z 72–78,
  3.41 mm under plate2's underside. 2047 mm long, 15.7 mm per °F average.
- The backplate was **deleted** — 968 × 937 × 6 mm was 43.8 kg and a solid wind sail,
  and the actuator's motor pod and clamp buried themselves in it (26,871 and
  5,094 mm³). A branching **frame** replaces it: flat, 8 mm, z −58..−50, front face
  25.4 mm behind rocker1 so it clears every link in z by construction. Total steel
  fell 48.5 → 15.9 kg.

## Things that cost time, recorded so they don't again

- **The scale can only be supported at 22 of 71 stations.** The first check said none:
  the scale IS the locus of Q, so plate2's arm sweeps over all of it. The escape is
  that a support post tops out at z = 72, below plate2's plane, so only the four
  lower links constrain it. The two clearest stations are 336 mm and 263 mm from any
  moving part.
- **plate1's P column pinches the scale** at one spot near 68 °F — 5.7 mm from the
  centreline, in 2 poses of 141. Any scale behind plate2 is crossed by plate2's own
  support column somewhere. Left unfixed at the owner's call; a small lateral kink in
  the bar costs nothing in reading accuracy, since the ring's centre is what reads.
- **Extruding every profile of a capsule-chain sketch fills the region the curve
  encloses.** The scale ridge came out 380,000 mm³ against a predicted 147,000 until
  the one 39,135 mm² island profile was filtered out by area. `print3d.py`'s STL
  ridge has the same shape of bug at much smaller scale.
- **`Occurrence.transform` and `transform2` both fail SILENTLY** for occurrences built
  with baked transforms in a parametric design. Rotating the assembly appeared to
  work and did nothing; the frame and posts moved and the mechanism did not. It was
  caught only because the interference check reported three pairs a rigid rotation
  cannot create. Rebuild at the new coordinates instead of trying to move.
- **The mounting orientation is `cfg.rot`, and it is not decoration.** The owner's is
  **170°** for shape-01. The model was first built at rot=0, which put the trunk
  180° out. Correct by rotating the design +170° about Z; verified by reading screen
  coordinates off the page at rot=170 and solving from two independent mount pairs,
  both giving +170.00°. **Ask for `cfg.rot` before deciding which way is up.**

# Making the full-scale assembly articulate (2026-08-09, late)

`kineticThermometer` now has **29 joints and drives**: push the actuator and the
whole mechanism follows, with the rod staying in its tube. Verified numerically —
`|R−ANCH|` matches `√((aClamp+e)² + off²)` to **0.0001 mm** across the entire
393.7 mm stroke, and the indicator Q lands on its expected point to **0.230 mm
median / 1.116 mm worst** over all 141 sample extensions.

## The actuator is a LINKED reference now, not a copy

The earlier SAT import was the root of a whole afternoon of wasted work. SAT is a
dumb solid format: it flattened the owner's three components into five loose bodies
in one component and **discarded the joints entirely**. Everything after that was
rebuilding, badly, something the source already had.

`Occurrences.addByInsert` had thrown `InternalValidationError` for every argument
combination, which is why the copy existed at all. **A Fusion update on 2026-08-09
fixed it** — on build 2705.0.87 both `isReferencedComponent=True` and `False`
succeed. Re-test it rather than assuming; the workaround is far worse than the
feature.

The owner's `Joyce QS11940 Linear Actuator` already contained `Slider 2` — rod↔tube,
Z axis, limits spanning exactly 406.4 mm = 16.0000″, the true stroke. Two things
were added to it (now **v11**): components renamed `Component1`→`tube`,
`Component2`→`rod`, and a **`clamp_slide`** slider so the clamp travels the tube over
`aClamp` 3.48″–24.66″, matching the drag handle the web tool exposes.

## aClamp is a design parameter and the insert must drive it

The clamp position is not fixed — the browser lets the user slide it, and `geo`
carries it (`aClamp`, 23.23″ for shape-01). `export_trace.py` already exported it;
what was missing was using it. The insert now:

1. computes the clamp pivot's local position for the exported `aClamp`
   (`z = 51 − aClamp_mm`, lateral offset 60.404),
2. builds the placement matrix from THAT, so clamp pivot → ANCH and rod pin → R,
3. drives `clamp_slide` to match, then **captures a position snapshot**,
4. only then creates the joints.

Skipping step 3 left a **0.133 mm** residual — exactly `aClamp` 23.23″ against the
model's as-drawn 23.2247″ — which had been visible for hours as an unexplained
rod-pin error and dismissed as rounding. It was not rounding.

## The clamp lock: host-side, and order-dependent

The clamp must be free in the source but fixed once installed. Locking it in the
source is wrong — it destroys the adjustability the part actually has.

The working recipe, and it is fussy:

- suppress `clamp_slide` **in the host assembly context** (`createForAssemblyContext`
  → `isSuppressed = True`), then create a host rigid joint `lock_clamp_to_tube`
  between the linked children — **both in the SAME script run**.
- The host-context suppression **does not survive between script runs**; read back in
  a later call it reports `False`. But the rigid joint, once created that way,
  persists through save and reload with `isSuppressed = False`.
- Attempting the two steps in separate runs always fails: the create is rejected as
  "a joint in system exists", and un-suppressing the lock while `clamp_slide` is live
  gets it auto-suppressed again on the next rebuild.

## A diagnosis worth remembering

With the clamp unlocked, driving the actuator produced `|R−ANCH|` **exactly** constant
at 593.126 mm. That was read as "the solver refuses, the loop is over-constrained".
It was the opposite: the loop was UNDER-constrained and `clamp_slide` was absorbing
the entire input — the rod extended by *e* relative to the tube while the tube slid
back through the clamp by the same *e*, so R never moved. **A perfectly constant
output under a varying input means absorption, not refusal.** The owner spotted this
from watching the model; three API-side hypotheses had missed it.

## Fusion API notes that cost real time

- **`JointDirections` resolve against the JOINT GEOMETRY's frame**, not the
  component's. Handing a slider the clamp's pin hole made it slide along the pin
  axis. Pick geometry whose normal IS the wanted direction — a circle edge on the
  tube gives the tube axis.
- **`CustomJointDirection` is ignored by `AsBuiltJointInput`.** Native construction
  axis, assembly-context proxy, cylindrical face and straight BRepEdge were all
  silently discarded (`customSlideDirectionEntity` reads `None`), falling back to
  world X for pin-slot and −Z for slider.
- **Driving a joint creates a pending position that later joint creation REVERTS**,
  undoing any placement done after it. `Design.snapshots.add()` captures it first.
- **`Document.save()` can return `True` and do nothing.** Verify by re-reading
  `dataFile.versionNumber` — and note `app.data.findFileById()` can return a stale
  cached DataFile, so `document.dataFile` is the more reliable read.
- **One file can be open twice with divergent in-memory contents**, one view showing
  the edits and the other the original. That state blocks saving. Close both and
  reopen a single clean view.
- **A reference update resets host-side overrides.** After
  `FusionDocument.updateAllReferences()` the sub-assembly joint came back
  unsuppressed and at its as-drawn position; the lock and the `aClamp` setting both
  had to be re-applied.

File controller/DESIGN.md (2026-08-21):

# Controller design — ongoing discussion

The electronics that drive the sculpture: temperature sensor → controller →
linear actuator position. The sim's temp→extension mapping (linear within the
excursion, optional reverse — see FABRICATION.md) is the spec this controller
must implement.

System bus: **12 V or 24 V** — the design must run on either. That choice
ripples through every section below (battery config, solar charge controller,
motor driver voltage ratings, buck regulator input range). *Note: the
off-the-shelf solar panel decision effectively pins this to 12 V — see
[Solar](#solar-interface-for-charging).*

Layout: `docs/` notes and datasheets, `src/firmware/`, `src/babysteps/`
(bring-up experiments), `src/web/`.

**Document rules (owner, 2026-08-20):** this file is the **single point of
truth** for the controller. Every research finding lands here — URLs, prices,
part numbers, measurements, decisions *and their rationale* — so no decision
ever gets rehashed and a future agent needs nothing from chat scrollback. If
research turns up a source, the source goes in this file.

**Provenance note:** a longer motor-driver selection conversation predates the
ChatGPT share linked in the Motor drivers section — the share opens mid-thread
("the parts we discussed"). Searched for on 2026-08-20 in this repo, this
project's session transcripts, and memory: not found. If the owner surfaces
the original thread, fold it in here.

---

## Contents

- [Decision summary](#decision-summary)
- [Hardware](#hardware)
  - [MCU](#mcu---decided-2026-08-20)
    - [Production board: ESP32-S3-WROOM module](#production-board-esp32-s3-wroom-module-on-the-controller-pcb---decided-2026-08-20)
      - [PCB reference: a WROOM board drawn end to end in KiCad](#pcb-reference-a-wroom-board-drawn-end-to-end-in-kicad--2026-08-21)
  - [Motor drivers (need 2)](#motor-drivers-need-2---decided-2026-08-20-ti-drv8245-q1)
  - [Temperature sensor](#temperature-sensor---decided-2026-08-20)
  - [Power supply](#power-supply---open)
  - [Battery and charger](#battery-and-charger---battery-decided-2026-08-20)
  - [Solar interface for charging](#solar-interface-for-charging)
  - [Enclosure](#enclosure---open)
- [Firmware](#firmware)
  - [Homing cycle and position feedback](#homing-cycle-and-position-feedback--required)
  - [Calibration](#calibration--required)
  - [Power management](#power-management)
  - [Dashboard](#dashboard)
  - [OTA updates](#ota-updates--required)
  - [Network / discovery](#network--discovery--required)
- [Features](#features)
  - [Walk-up forecast mode](#walk-up-forecast-mode---proposed-2026-08-20)

---

## Decision summary

Status markers used throughout: ✅ decided · 🔶 open · 💡 proposed

| Topic | Status | Decision |
|---|---|---|
| MCU, bring-up | ✅ 2026-08-20 | ESP32 DevKitC (owner has many) |
| MCU, production | ✅ 2026-08-20 | ESP32-S3-WROOM-1 module on the controller PCB |
| Battery | ✅ 2026-08-20 | 12 V 7 Ah UPS-style sealed AGM |
| Solar panel | ⏸ deferred 2026-08-20 | Retail trickle maintainer, **5 W tier** — see [Panel research round 2](#panel-research-round-2-2026-08-20); top pick on record: SUNER POWER BC-5W Pro. Load ≤2.5 Wh/day (WiFi always on), so 5 W is the smallest framed+weatherproof+float-regulated retail box, not a capacity need. Undersized → customer buys bigger |
| Temperature sensor | ✅ 2026-08-20 | TI TMP117 |
| Bus voltage | 🔶 | 12 V or 24 V required; retail panel choice pushes 12 V — confirm |
| Motor driver | ✅ 2026-08-20 | TI DRV8245-Q1 — quality over cost |
| Charge controller | 🔶 | Must float-regulate SLA; pick with the panel |
| Forecast provider | 🔶 | NWS/weather.gov leading (free, keyless, US-only) |
| Walk-up forecast mode + servo dial | 💡 | Proposed feature, spec'd below |

---

## Hardware

### MCU — ✅ decided 2026-08-20

**Bring-up: ESP32 DevKitC** — owner has plenty on hand. Board references in
`docs/`: DevKitC v4 schematic, DOIT-variant schematic, and two pinout images.

#### Production board: ESP32-S3-WROOM module on the controller PCB — ✅ decided 2026-08-20

Skip the daughter-card-and-header-pins arrangement entirely: solder an
**ESP32-S3-WROOM-1 module** down on the controller PCB itself. Owner's
verdict on module-vs-bare-chip: "a no-brainer" — the module carries flash,
RF matching and antenna built in, is FCC/CE **pre-certified** as an
intentional radiator (key for the for-sale version), and is stocked at
LCSC / assembled at JLC (table below). The bare-chip + own-PCB-antenna route
(cheaper BOM, but we'd own RF layout and radio certification) is **rejected**.

**LCSC/JLC availability (checked 2026-08-20): yes** — same pipeline as the
motor drivers:

| Variant | LCSC # | Notes |
|---|---|---|
| ESP32-S3-WROOM-1-N8 | C2913198 | 8 MB flash, ~$3.03, in stock |
| ESP32-S3-WROOM-1-N16 | C2913199 | 16 MB flash |
| ESP32-S3-WROOM-1-N8R8 | C2913201 | 8 MB flash + 8 MB PSRAM |
| ESP32-S3-WROOM-1-N16R8 | C2913202 | 16 MB flash + 8 MB PSRAM |
| ESP32-S3-WROOM-1U-N8 | C2980297 | U = external-antenna connector version |

The N8 covers this firmware easily (web UI + OTA needs dual app partitions —
8 MB is roomy; PSRAM is for camera/LLM-class loads we don't have). The 1U
variant is the escape hatch if the metal sculpture ends up shadowing the
on-module antenna.

S3 side benefits over the classic ESP32: native USB (no CP2102 bridge), and
none of the devkit's AMS1117/USB-bridge quiescent draw — the board can be
designed to actually reach the low-power numbers the Power-management
section wants.

Plan: **DevKitC for bring-up (`src/babysteps/`), integrated S3 board as the
production design.**

Sources (checked 2026-08-20):

- N8 at LCSC (~$3.03, in stock): <https://lcsc.com/product-detail/WiFi-Modules_Espressif-Systems-ESP32-S3-WROOM-1-N8_C2913198.html>
- N16R8 at LCSC: <https://www.lcsc.com/product-detail/WiFi-Modules_Espressif-Systems-ESP32-S3-WROOM-1-N16R8_C2913202.html>
- JLC assembly listing (N16R8 example): <https://jlcpcb.com/partdetail/3198300-ESP32_S3_WROOM_1N16R8/C2913202>
- Module datasheet: <https://www.espressif.com/sites/default/files/documentation/esp32-s3-wroom-1_wroom-1u_datasheet_en.pdf>
- Espressif hardware design guidelines (schematic/layout/antenna keep-out): <https://docs.espressif.com/projects/esp-hardware-design-guidelines/en/latest/esp32s3/>

#### PCB reference: a WROOM board drawn end to end in KiCad — 2026-08-21

Video reference for drawing this board: *"ESP32-S3 Simple TestBoard designed in
KiCad"*, **made by morten**, 2:29:31, uploaded 2026-08-21 —
<https://www.youtube.com/watch?v=Z5AQMZh3qXw>. An unbroken real-time build of an
ESP32-S3-WROOM-1 board: blank schematic → symbols → footprints → BOM →
45 × 45 mm 4-layer stackup → routing → copper zones → silkscreen → DRC →
Gerbers → fab upload. Machine-transcribed here 2026-08-21 (Whisper
`large-v3-turbo`); digested notes with a timestamp index in
[`docs/video-kicad-esp32s3-morten.md`](docs/video-kicad-esp32s3-morten.md), full
transcript in
[`docs/video-kicad-esp32s3-morten-transcript.md`](docs/video-kicad-esp32s3-morten-transcript.md).
His board is orderable at
<https://www.pcbway.com/project/shareproject/ESP32_S3_SIMPLE_TestBoard_b77edcef.html>.

The findings that touch decisions in this document:

- **PSRAM costs three GPIOs.** On `-R8` (octal-PSRAM) WROOM variants **IO35,
  IO36 and IO37 are used internally** and are unusable. We chose the N8, so they
  are ours — but the `1U`/R8 escape hatch above stops being free the moment
  firmware hard-codes them. Keep IO35–37 unassigned if it costs nothing.
- **Strapping pins**: GPIO0, GPIO3, GPIO45, GPIO46. We have pins to spare —
  don't use them. GPIO3 takes a 10 kΩ pull-up; GPIO0 + EN + RX/TX belong to the
  programming header.
- **EN/reset network**: button EN→GND, 10 kΩ pull-up, 1 µF EN→GND for the reset
  RC, **and an ESD diode on EN** because a finger reaches that button. That last
  part generalises: the walk-up forecast button below is a user-touched GPIO on
  an outdoor metal sculpture, so **every user-facing GPIO gets an ESD part**.
- **Decoupling**: 10 µF + 100 nF at the module, with the **100 nF closest to the
  module VCC pin** in layout.
- **Qwiic (JST SH 4-pin, SM04B-SRSS-TB) for the I²C sensor** — pin 1 GND, 2 VCC,
  3 SDA, 4 SCL; pull-ups **2.2 kΩ** (10 k was drawn and corrected); default S3
  I²C is IO8 SDA / IO9 SCL. 💡 This is the tidy way to put the **TMP117** on a
  cable, off the board and out of its self-heating — spec at
  <https://www.sparkfun.com/qwiic>. 🔶 Open: whether the sensor hangs on a Qwiic
  cable or gets its own sealed gland-and-terminal run, given the outdoor
  environment (JST SH is an indoor connector).
- **A 6-pin ESP-Prog programming header** (EN, TXD, RXD, 3V3, GND, IO0) is a
  complete substitute for on-board USB-UART. We picked the S3 partly *for*
  native USB, so this is not a replacement — but footprinting the header is
  cheap insurance if native-USB bring-up stalls.
- **4-layer stackup that suits us**: top signal / In1 **GND plane** / In2
  **3V3 plane** / bottom signal. Zone settings used: clearance 0.2 mm, thermal
  gap 0.2 mm, spoke 0.3 mm.
- **Workflow**: assign footprints in the *schematic* editor (Tools → Edit Symbol
  Fields), not the PCB editor, so the PCB can't silently substitute one; the same
  dialog carries custom BOM columns (distributor part numbers) and the
  exclude-from-BOM / DNP flags. Annotate before the final BOM export.

**Do not treat it as a template for the whole controller PCB.** It is a
milliamp signal board: linear LM1117 from 5 V (not our 12 V buck), 0.6 mm
"power" tracks, no motor drivers, no high-current copper or thermal work, no
return-path/plane splitting, no impedance control (skipped even on USB), and
nothing about surge, reverse-polarity or transient protection on field wiring.
Those are the hard parts of *our* layout and this video does not touch them.

---

### Motor drivers (need 2) — ✅ decided 2026-08-20: TI DRV8245-Q1

Two driver channels required. The shortlist below was compiled for one
channel at 3–5 A continuous; whatever is chosen, use two (or a dual-channel
part covering both).

**Current sensing is a hard requirement** (added 2026-08-20): the homing
cycle detects the actuator's internal end stops by the motor current
dropping to zero (see [Homing](#homing-cycle-and-position-feedback--required)).
The chosen driver must expose motor current to the ESP32 — the DRV8245's
integrated current-sense mirror fits this exactly; for others, check for a
current-sense pin or budget an external shunt.

**24 V check needed**: the shortlist was drawn up before the 12-or-24 V
requirement. DRV8245 (4.5–35 V) and MP6615 (4.75–40 V) cover a 24 V bus with
headroom; the VNH7070 is an automotive 12 V-class part — verify its max
supply rating before keeping it on a 24 V design. (Moot if the bus is pinned
to 12 V by the solar decision.)

#### Shortlist (from ChatGPT "Motor Driver Stock Watch", summarized 2026-08-20)

Source: <https://chatgpt.com/share/6a87cd95-d654-83e8-84fd-84b7e82c4eb0>

Goal: an integrated H-bridge, orderable through LCSC and assemblable at JLC.
LCSC exposes live price tiers; JLC only shows unit price during
BOM/pre-order, so all prices below are LCSC (USD, checked 2026-08-15).

| Part | LCSC # | Stock | 1 pc | 100 pcs | Verdict |
|---|---|---|---|---|---|
| TI DRV8245HQRXZRQ1 | C5218845 | 224 | $7.73 | $6.09 | Best overall choice |
| ST VNH7070ASTR | C2150622 | 2,209 | $3.93 | $2.74 | Best value / availability |
| Infineon IFX9201SG | C112633 | 427 | $4.30 | $2.77 | Reasonable, not first choice |
| NXP MC33926PNB | C1556870 | 43 | $8.14 | $6.34 | Expensive and old; avoid |
| MPS MP6615GQKT-Z | — | — | — | — | No LCSC listing at first check |
| MPS MP6612GF-Z | — | — | — | — | No LCSC listing |

Reasoning:

- **DRV8245** — best engineering choice: newest architecture, ~32 mΩ bridge
  resistance, 4.5–35 V, built-in current sensing/regulation, compact VQFN.
  Costs ~$3.35 more per unit than the VNH7070 at qty 100.
  Ratings clarified 2026-08-20 (owner asked "is it a 32 A device?"): yes —
  TI headlines it as a **40-V, 32-A peak** H-bridge; the identical "32" in
  mΩ and A is coincidence. At our 3–5 A continuous it has huge margin;
  32 A is peak/stall handling, continuous is thermally limited far above
  our operating point. Datasheet:
  <https://www.ti.com/lit/ds/symlink/drv8245-q1.pdf>
- **VNH7070** — best cost/availability: $2.74 @100, 2,200+ in stock,
  15 A-class integrated bridge, ~70 mΩ RDS(on).
- **IFX9201** — worth considering only if its SPI diagnostics appeal.
- **MC33926** — costs more than the DRV8245 with dramatically higher losses
  and a larger package; do not design in.

**Follow-up update** (same thread, later check): the **MP6615 is now in the
LCSC/JLC ecosystem** as **C22697501** — TQFN-26 6×6 mm, SMT Extended Library,
4.75–40 V, 8 A continuous, 11 mΩ per MOSFET, ~¥28.08 (≈$3.90). DRV8245 stock
improved to 248. That makes the MP6615 a real third contender it wasn't at
the first check.

#### Decision — ✅ TI DRV8245-Q1 (2026-08-20)

Owner: "a no-brainer. I'm not too concerned about the cost of the device.
I'm more concerned about the quality." The ~$3.35/unit premium over the
VNH7070 is accepted. Rationale:

- Newest part on the list: datasheet SLVSFJ1E dated **November 2021**
  (rev. June 2026), TI's current-generation DRV824x-Q1 automotive family.
  The ST VNH7070AS is a mid-2010s design (~2016); the NXP MC33926 is
  2008-era.
- **Datasheet-verified 2026-08-20** (PDF pulled and read, first 3 pages):
  I<sub>OUT</sub> max **32 A**, R<sub>ON</sub> **32 mΩ** in VQFN-HR-16 (the
  LCSC part's package; HTSSOP-28 variant is 40 mΩ/32 A), 4.5–35 V operating,
  40 V abs max, **integrated current sense with proportional IPROPI output**
  — exactly what the homing cycle's current-drop detection needs, no
  external shunt. Huge margin at our 3–5 A.
- LCSC C5218845, ~$6.09 @100 (2026-08-15 pricing above).

Note: the owner asked whether the TI part is newer than "the Toshiba part" —
**no Toshiba device was in this shortlist**; the nearest intended comparison
is the ST VNH7070. If a Toshiba TB67-series part was discussed, it was in
the unrecovered pre-share thread (see Provenance note).

The question this closed, kept for the record: *at 3–5 A continuous, does
the DRV8245's thermal advantage (~32 mΩ vs the VNH7070's ~70 mΩ) justify
~$3.35/unit? And does the MP6615's 11 mΩ/FET at ~$3.90 undercut both?*
Answer: moot — cost was dropped as a criterion; quality/newness decided it.
The full shortlist, per-part reasoning, prices, and the MP6615 follow-up
remain above; the VNH7070 (best value) and MP6615 (best mΩ/$) stay recorded
as the fallbacks if the DRV8245's supply ever dries up.

Part references:

- TI DRV8245-Q1 product page: <https://www.ti.com/product/DRV8245-Q1>
- ST VNH7070AS product page: <https://www.st.com/en/automotive-analog-and-power/vnh7070as.html>
- MPS MP6615: <https://www.monolithicpower.com/> (search MP6615)
- LCSC part pages resolve from the C-numbers in the table, e.g.
  <https://www.lcsc.com/search?q=C5218845>

---

### Temperature sensor — ✅ decided 2026-08-20

**TI TMP117** — I²C, 1.8–5.5 V supply, wired to the ESP32's I²C. Accuracy
**±0.1 °C over −20 to +50 °C** — owner reviewed that figure and accepted it
as sufficient for this sculpture (2026-08-20). Product page / datasheet:
<https://www.ti.com/product/TMP117>

🔶 Open: outdoor placement/housing (radiation shield, cable run) so it reads
air temperature, not enclosure temperature — and outside the electronics
enclosure's self-heating (see [Enclosure](#enclosure)).

---

### Power supply — 🔶 open

Battery bus (12 V or 24 V) → logic rails for the ESP32 and sensors.

- Needs a wide-input buck covering both buses (roughly 9–30 V in) → 5 V for
  the DevKitC's VIN, which regulates 3.3 V on-board.
- 🔶 Open: part selection, quiescent draw (this runs 24/7 outdoors — idle
  current matters more than peak), reverse-polarity and surge protection at
  the battery input.

---

### Battery and charger — ✅ battery decided 2026-08-20

**Lead-acid, UPS-style:** the standard 12 V 7 Ah sealed AGM brick
(CSB GP1272 / Power-Sonic PS-1270 / Yuasa NP7-12 — interchangeable,
~$20–30). Case 151 × 65 × 94 mm, F2 faston terminals preferred. Charges fine
below freezing, unlike LiFePO4 — right for a −20 °F outdoor piece.
One battery = 12 V bus; two in series = 24 V (exactly how 24 V UPSes are
built). Float 13.6–13.8 V, cycle 14.4–14.7 V per battery.

- 🔶 Open: capacity check — is 7 Ah enough for actuator duty cycle + ESP32
  idle draw through winter nights? Same case family goes to 9 Ah (e.g.
  PS-1290) if not.
- 🔶 Open: charger — likely combined with the solar charge controller rather
  than a separate unit.

Sources (checked 2026-08-20):

- CSB GP1272F2 (the APC OEM cell): <https://www.amazon.com/CSB-GP1272F2-Volt-Sealed-Battery/dp/B00HKJ1FW6>
  and <https://www.osibatteries.com/csb-gp1272f2-battery-12v-7-2ah-sealed-lead-acid>
- Power-Sonic PS-1270F1 at Home Depot: <https://www.homedepot.com/p/12-Volt-7-Ah-F1-Terminal-Sealed-Lead-Acid-SLA-Rechargeable-Battery-PS-1270F1/312948092>
- Yuasa NP7-12: <https://www.amazon.com/Yuasa-NP7-12-Sealed-Battery-Terminal/dp/B00FA61Q1G>

---

### Solar interface for charging

> **Read [Panel research round 2](#panel-research-round-2-2026-08-20) at the
> end of this section first.** The load was restated on 2026-08-20 (ESP32
> duty-cycled, 1 s awake per 30 s → ~0.5 Wh/day), which supersedes the 10 W
> recommendation below and re-targets the panel to the **5 W** tier.
> Everything between here and there is kept as the record of how the earlier
> number was reached, and the round-1 candidate list did not survive re-check.

**STATUS 2026-08-20: panel decision DEFERRED (owner).** Assume some
5–10 W retail trickle charger that is suitable, easily available, and
replaceable; pick the exact model later. If a customer's panel proves too
small for their site, they buy a bigger one — that's the virtue of the
off-the-shelf decision. The power analysis in Firmware → Power management
puts the load at ≤2.5 Wh/day with WiFi always on, so any 5–10 W maintainer
has multiples of margin. Everything below (budget history, sizing math,
candidates, remote placement, cautions) stands as research for that later
pick — none of it blocks the rest of the design.

#### Energy budget (researched 2026-08-20)

Operating scheme (owner): firmware polls the TMP117 continuously and moves
the motor only on a **≥1° change** — short ~1 A @ 12 V bursts, MCU-only the
rest of the time.

- **Motor: negligible.** 1°F ≈ 0.12″ of extension (15.5″ over ~130 °F);
  at a rough 0.5″/s that's ~0.25 s × 12 W ≈ 3 J per move. Even 100 moves
  plus a full homing stroke is **< 0.5 Wh/day**.
- **ESP32 DevKitC: dominates.** Community measurements: ~**40 mA @ 5 V
  average WiFi-connected with modem sleep** (spikes ~150 mA), so ~0.2 W;
  light sleep drops the board to 2–5 mA, floored by the DevKitC's AMS1117
  LDO (~5 mA quiescent) and USB bridge. With buck overhead, design at
  **0.25–0.5 W continuous → 6–12 Wh/day**. This, not the motor, sizes the
  panel — and night light-sleep roughly halves it.

Design number: **~7 Wh/day** (modem-sleep days, light-sleep nights),
**~15 Wh/day** worst case (always fully on).

**REVISED 2026-08-20 — production S3 board changes this.** The figures
above assumed the DevKitC always-on (AMS1117 + USB-bridge leakage, no sleep
discipline) and the owner rejected them as the sizing basis ("we can power
everything down… we're not going to consume 15 Wh a day"). On the custom
S3 board with sleep modes: WiFi up with modem sleep during the day only
(~0.1 W × ~12 h ≈ 1.2 Wh), light/deep sleep nights (mW-level), µA-level
TMP117 polling → realistic **~1–3 Wh/day**. New design number: **3 Wh/day**.
The old 7–15 Wh numbers stay above as the record of what the *devkit* would
burn, and as the bound if firmware power management never ships.

Policy caveat that actually drives this budget: mDNS/dashboard reachability
requires the WiFi radio listening — 🔶 pick a policy (daytime-on/night-off
is the assumption behind 3 Wh/day; always-reachable costs ~2× that).

**REVISED AGAIN 2026-08-20 — owner set the operating model:** temperature
doesn't change that fast; **wake every 30 s, run ~1 s, sleep the rest**
(~3% duty cycle). Budget: ~3% × ~60 mA active + deep-sleep floor ≈ ~2 mA
average @ 3.3 V ≈ **~0.5 Wh/day** all-in, including a handful of WiFi
sessions (forecast fetches, occasional dashboard use) and motor bursts.
This is the **current design number: 0.5 Wh/day**.

Consequence: a deep-sleeping ESP32 is NOT reachable by mDNS/dashboard
between wakes. Resolution: the walk-up **button is an RTC-GPIO wake
source** — a press wakes the device and brings WiFi up for a service
window (e.g. 10 min) for the dashboard/calibration; forecast fetches run
on schedule during a wake. 🔶 Confirm the service-window length and
whether any additional scheduled WiFi windows are wanted.

ESP32 consumption sources (checked 2026-08-20):

- Dev-board measurements (40 mA WiFi-connected w/ modem sleep, ~150 mA
  spikes every 100 ms; light sleep 2–5 mA floored by the AMS1117's ~5 mA):
  <https://hubble.com/community/guides/esp32-power-consumption-datasheet-vs-reality/>
- Sleep-mode overview: <https://lastminuteengineers.com/esp32-sleep-modes-power-consumption/>
  and <https://deepbluembedded.com/esp32-sleep-modes-power-consumption/>
- Forum thread with measured numbers: <https://esp32.com/viewtopic.php?t=2662>

#### Panel sizing

Usable harvest ≈ rated W × peak-sun-hours × ~0.7 (controller, dust, angle).

| Scenario | Winter peak-sun-hrs | 5 W panel | 10 W panel |
|---|---:|---|---|
| Owner (SW Colorado, excellent sun) | ~4 | ~14 Wh/day ✓ | ~28 Wh/day ✓✓ |
| Northern customer (Seattle/New England Dec) | ~1–1.5 | ~4 Wh/day ✗ | ~8 Wh/day — enough **only with night light-sleep** |

Size reality check on the owner's 5×5″/6×6″ guess: 6×6″ of cell at ~20%
efficiency is only ~4.6 W theoretical — commercial panels run bigger:
**5 W ≈ 12.6×6.3″, 10 W ≈ 13.3×8.1″** (standard 12 V "battery maintainer"
panels, IP65, ~$20–35).

**Recommendation (superseded):** the first pass recommended a 10 W panel —
sized against the DevKitC's 7–15 Wh/day worst case for a northern-winter
customer. The owner challenged it as overkill ("the panels are gonna be
huge") — correctly, once the budget was re-based on the production S3 board.

**Recommendation (current, 2026-08-20): 5 W** (~12.6×6.3″). At the 30-s
duty-cycle budget (**~0.5 Wh/day**) even a 2–3 W maintainer balances a
northern December (3 W × 1.2 PSH × 0.7 ≈ 2.5 Wh/day), so wattage is no
longer the constraint — 5 W stays the pick because at retail it is the
smallest tier that reliably comes framed, weatherproof, and with real
float regulation; the 1.5–2.5 W dashboard-style trickle panels are often
unregulated. 10 W is documented insurance only (firmware power management
slips, or an exceptionally bad site). Battery reserve at 0.5 Wh/day:
7 Ah × 12 V = 84 Wh, ~42 Wh usable at 50% DoD → **months** of autonomy;
the battery outlasts any plausible cloudy stretch.

Panel-size sources (checked 2026-08-20): 5 W = 12.6×6.3″
(<https://www.acopower.com/products/hy005-12m>), 10 W = 13.3×8.1×0.7″
(<https://www.amazon.com/ECO-WORTHY-Battery-Charger-Portable-Electrical/dp/B00OZC3X1C>),
sizing guidance <https://voltagebasics.com/what-size-solar-panel-to-trickle-charge-a-12v-battery/>

#### Panel: off-the-shelf retail only — ✅ decided 2026-08-20

Owner's call: **no bare panels, no custom panel enclosure.** Use a consumer
"tractor battery maintainer"-style product the customer can buy and replace
themselves if it breaks — we recommend models rather than bundle glass. The
criterion is **easy retail availability**, not any one store: Harbor Freight
was an example; Amazon, Walmart, REI, Big 5, an auto-parts store — anywhere
common works. Candidates (all 10 W, 12 V, framed/weatherproof, checked
2026-08-20):

| Product | Where | Price | Notes |
|---|---|---|---|
| Harbor Freight Thunderbolt Solar 10 W Trickle Charger (SKU 70830) | Harbor Freight | $44.99 reg, routinely $25–35 on coupon | The owner's named example; framed panel |
| ECO-WORTHY 10 W maintainer kit | Walmart, Amazon | ~$27–33 | Panel + charge controller + adjustable mount bracket + SAE/clip cables — most complete kit |
| Renogy 10 W trickle maintainer | Amazon, renogy.com | ~$30–40 | SAE + lighter plug + clips; reputable brand |

Wiring is easy in every case: they all terminate in an SAE pigtail with
clip/ring adapters — land it on the battery terminals.

Candidate sources (checked 2026-08-20):

- HF Thunderbolt 10 W (SKU 70830): <https://www.harborfreight.com/10-watt-solar-trickle-charger-70830.html>
  — coupon/price history: <https://hfpricetracker.com/tools/70830>
- ECO-WORTHY 10 W kit (panel + controller + bracket + SAE):
  <https://www.amazon.com/ECO-WORTHY-Controller-Maintainer-Waterproof-Adjustable/dp/B0CSMX7PTL>
  — also at Walmart: <https://www.walmart.com/ip/2718794859>
- Renogy 10 W: <https://www.renogy.com/products/10w-solar-battery-trickle-charger-maintainer>
  — also <https://www.amazon.com/Renogy-Solar-Battery-Maintainer-Trickle/dp/B07QBY7626>

#### Remote panel placement

The customer may site the panel away from the sculpture — to hide that the
piece is solar-powered, or because the sculpture itself sits in shade (a
garden nook, north side of the house) while the panel needs sun. Either way
the wire run may be **buried**. Provide for it:

- Voltage drop is mild at trickle current (~0.6 A), but spec a wire table
  anyway — e.g. 18 AWG to ~25 ft, 14 AWG to ~100 ft — since maintainer
  pigtails are short and thin.
- The extension must be outdoor/direct-burial rated (UF cable, or low-voltage
  landscape-lighting wire in conduit); splice to the panel's SAE pigtail
  with a weatherproof junction.
- Put the charge controller at the **battery end**, not the panel end, so
  the buried run's drop doesn't skew the float voltage.

#### Two cautions

- These maintainers assume a big car battery. Into our small 7 Ah SLA, a
  10 W panel is ~C/12 — a bare blocking-diode panel would overcharge it.
  **Require real float regulation**: either a maintainer with a built-in
  controller (the ECO-WORTHY kit ships one) or add a small inline PWM
  controller with an SLA profile (13.6–13.8 V float). MPPT buys nothing
  under 20 W.
- **These products are all 12 V-only — choosing them effectively pins the
  bus to 12 V** (one battery, no series pair). That simplifies everything
  else; 🔶 confirm in the bus decision.

#### Panel research round 2 (2026-08-20)

**The sizing premise changed on this date, so read this subsection over the
one above.** The owner restated the load: the ESP32 is **duty-cycled, 1 s
awake per 30 s**, motor bursts still negligible → **~0.5 Wh/day** total, not
the 7–15 Wh/day the "Energy budget" subsection above assumed for an always-on
MCU. That earlier budget is kept for the record (it is what an always-on
DevKitC really costs) but it no longer sizes the panel.

*Reconciliation note (added after this research ran): the owner has since
replaced the 30-s duty-cycle model with WiFi-always-on + DFS at
**≤2.5 Wh/day** (see Firmware → Power management). Every conclusion below
survives that change — 5 W × 1.2 PSH × 0.7 ≈ 4.2 Wh/day still clears the
worst site — only this paragraph's 0.5 Wh figure is dated.*

At 0.5 Wh/day, **capacity stopped being the constraint.** Even 2 W balances
the worst customer site: 2 W × 1 peak-sun-hour × 0.7 derate = 1.4 Wh/day, ~3×
the load. So the 10 W recommendation above is superseded — not because 10 W
is wrong, but because it is 20× more panel than the load needs and the owner
wants the panel visually unobtrusive in a garden.

**Why 5 W is still the floor, and it is a market fact rather than an
electrical one.** Below ~5 W the retail category stops being framed
glass-and-aluminium maintainers and becomes dashboard/amorphous trickle
panels: a cell, a blocking diode, suction cups, and no regulator at all. That
is precisely what a 7 Ah SLA must never see. Every sub-5 W product checked
below (Schumacher 2.4 W, and Harbor Freight's discontinued 1.5 W) is
unregulated, and the amorphous ones are physically **larger** than a 5 W mono
panel despite making half the power. 5 W mono is the smallest size where
framed + weatherproof + float-regulated all arrive in one box.

**All three round-1 candidates fail on re-check.** This is the main result of
round 2:

- **ECO-WORTHY 10 W kit (B0CSMX7PTL)** — the round-1 "most complete kit" — is
  **Currently unavailable** on Amazon ("We don't know when or if this item
  will be back in stock"), checked 2026-08-20. The ECO-WORTHY 10 W that *is*
  in stock (B017K6PH1S, $29.99, 6,457 ratings) is a **different, unregulated
  product** — its feature bullets say "built-in blocking diode", the spec box
  lists an 18.7 V output, and no controller is claimed.
- **Renogy 10 W** is two problems. On renogy.com the RSP10TC is $39.99 and
  listed **Unavailable** in the clearance section. The in-stock Amazon item
  (B07QBY7626, $24.94) is a **fabric/PET windshield panel, not framed or
  weatherproof** — Amazon's own review summary flags "the fabric disintegrates
  in sunlight and it's not weatherproof" — and a detailed verified review from
  a van-electrical installer reports **no voltage regulation at all**, taking
  a 9 Ah battery past 15.5 V, with Renogy's manual itself saying not to leave
  it connected unattended. Fails requirements 1 and 3.
- **Harbor Freight Thunderbolt 10 W (SKU 70830)** survives but with two
  caveats found in its manual and listing: it is **In-Store Only** (no
  shipping — the customer needs an HF within driving distance), and its rated
  output is **"14.6 VDC Max"** with an LED-driven cutoff, i.e. an
  absorption-voltage on/off clamp, **not a 13.6–13.8 V float**. The manual
  also says it is "intended only to keep a fully charged battery from losing
  its charge. It will not work to charge a battery that is discharged", and
  warns "Do not leave battery clips attached indefinitely" — awkward wording
  for a product that is our *only* charger.

**No 5 W sibling exists for any of the three.** Harbor Freight's 1.5 W
maintainer (SKU 64251 / 62449 / 44768 / 68692) 404s and is absent from HF's
own solar search results — discontinued; HF's small-panel line is the 10 W
alone. ECO-WORTHY's small units (7.5 W $24.99, 5 W, 2.5 W) are the
blocking-diode family, not the controller kit. Renogy's 5 W is the same
fabric windshield panel in a smaller size.

##### Comparison table (all prices and stock checked 2026-08-20)

| Product | W | Panel size (in) | Price | Retailer(s) | Controller? | Connector / lead | Bracket? | Warranty | URL |
|---|--:|---|---|---|---|---|---|---|-----|
| **SUNER POWER BC-5W Pro** | 5 | *unverified* — omitted from both the Amazon spec table and the maker's page | $49.99 Amazon / $49.95 maker | Amazon (In Stock, sold by SUNER POWER, FBA); sunerpower.com | **Built in** — MPPT, "3-stages (Bulk, Absorption, Float)" | SAE; 3-piece SAE cable kit (clips / rings / lighter). Lead length unverified; the 10 W sibling is 9.8 ft | No — "Pro" is the portable trim; bracket models sold separately | 12 mo + lifetime tech support (maker) | <https://www.amazon.com/SUNER-POWER-Waterproof-Maintainer-UltraSmart/dp/B0DRFGBX5J> · <https://sunerpower.com/products/bc-5w-solar-battery-charger-pro> |
| **POWOXI 7.5 W** | 7.5 | 14.76 × 9.06 × 1.89 | $37.99 (list $44.99) | Amazon (In Stock, 6.4K ratings); POWOXI has a Walmart brand page | **Built in** — "Upgrade Intelligent Charge Controller"; setpoints unpublished | SAE + cigarette lighter + alligator clips; lead length unverified | Not stated | 12 mo | <https://www.amazon.com/Battery-Portable-Waterproof-Maintainer-conversion/dp/B07JLWFPX6> |
| **SUNER POWER 10 W (B07XNZZHK5)** | 10 | 13.8 × 9.2 × 0.7, 3.4 lb | $59.95 | Amazon (In Stock, FBA, 721 ratings) | **Built in** — MPPT, 3-stage bulk/absorption/float | SAE harness, **3 m / 9.8 ft** — longest verified stock lead here | **Yes** — 360° adjustable ball mount | unverified (12 mo per maker's other listings) | <https://www.amazon.com/SUNER-POWER-Waterproof-Battery-Maintainer/dp/B07XNZZHK5> |
| HF Thunderbolt Solar 10 W (SKU 70830) | 10 | 13.8 × 8.8 × 1.0, IP65, 600 mA | $44.99 (ITC coupon $34.99 expired 2026-07-03; historic low $24.99) | Harbor Freight — **In-Store Only**, in stock Montrose CO aisle 5 | Built in, but **14.6 VDC max cutoff, not a float** | SAE, **8 ft** + clip / ring / 12 V-outlet adapters | Suction cups (4) + carabiners (2) only | 90 days | <https://www.harborfreight.com/10-watt-solar-trickle-charger-70830.html> |
| Callsun 7.5 W | 7.5 | *unverified* | $19.98 (list $21.99) | Amazon (sold by Callsun-US, 165 ratings) | Claimed built in — "IP68 Smart Controller"; **unverified**, not inspected past Amazon's comparison module | SAE-to-SAE | unverified | unverified | (Amazon comparison module on <https://www.amazon.com/Renogy-Solar-Battery-Maintainer-Trickle/dp/B07QBY7626>) |
| Battery Tender 5 W (021-1171) | 5 | *unverified* | $74.95 maker (**Sold out**) / $54.55 Amazon | batterytender.com **sold out**; Amazon; Battery Tender has the broadest auto-parts distribution of any brand here | **Built in** — 3-step microprocessor w/ temperature compensation | Quick-disconnect harness; ring/clip leads sold separately ($12.95 / $15.95) | Windshield mount | **5 yr** | <https://www.batterytender.com/collections/solar-panels> |
| ECO-WORTHY 10 W kit (B0CSMX7PTL) | 10 | 14 × 8.86 × 1.38, IP65 | — | Amazon: **Currently unavailable** | Built in (3-stage per user reports) | SAE, 200 cm + 50 cm clip and ring adapters | Yes — 360° metal | unverified | <https://www.amazon.com/ECO-WORTHY-Controller-Maintainer-Waterproof-Adjustable/dp/B0CSMX7PTL> |
| Battery Tender 10 W (021-1164) | 10 | 28 × 14 × 1 (amorphous — huge) | — | **Discontinued**: absent from batterytender.com; Amazon "Currently unavailable" | Built in, 3-step | 8 ft cord | — | 5 yr | <https://www.amazon.com/Battery-Tender-021-1164-Maintainer-Microprocessor/dp/B004Q86JJ8> |

##### Top 2 recommendations

1. **SUNER POWER BC-5W Pro — $49.99, Amazon, in stock.** The only verified
   5 W product that is framed, weatherproof, and genuinely **float**-regulated
   (a published bulk/absorption/float 3-stage controller, which is exactly
   requirement 3), on an SAE pigtail, Amazon-fulfilled so a customer can
   replace it in two clicks. Buy one and measure it before designing a mount —
   its dimensions are published nowhere.
2. **POWOXI 7.5 W — $37.99, Amazon, in stock.** The second source, from a
   different vendor, and the cheapest regulated unit verified in stock, with
   6,457 ratings behind it. It costs ~20 % more panel area than the 5 W and
   its controller's setpoints are unpublished — take it as the fallback if
   SUNER POWER is out, not as the first pick.

**Bracket-included variant of #1:** the **SUNER POWER 10 W (B07XNZZHK5),
$59.95** — same controller family, dimensions actually published
(13.8 × 9.2 × 0.7″), and it ships the 360° mount and a 9.8 ft SAE lead. Worth
$10 and ~3″ of extra width if the mount and the long lead save fabrication;
the extra 5 W buys nothing at 0.5 Wh/day.

##### Disqualified, with the reason (so these don't get re-proposed)

- **Renogy 10 W (B07QBY7626), $24.94, in stock** — fabric windshield panel,
  not framed/weatherproof; **no voltage regulation**. Fails req 1 and 3.
- **Renogy RSP10TC (renogy.com), $39.99** — listed **Unavailable**, clearance.
- **ECO-WORTHY 10 W (B017K6PH1S), $29.99, in stock** — **blocking diode
  only**, 18.7 V listed output. Would need an inline controller added.
- **ACOPOWER 5 W HY005-12M, $22.90** — 12.6 × 6.3 × 1.0″, IP65, framed,
  10-yr workmanship / 25-yr output warranty, and it is the source of the
  "5 W ≈ 12.6 × 6.3″" figure cited earlier in this section. But it is a
  **bare panel**: no controller, no maintainer cabling. Fails req 1 and 3.
  Good size reference, not a product we can point a customer at.
- **Coleman / Sunforce 6 W (58022)** — 18 × 14.5 × 1.5″ amorphous for 6 W,
  **blocking diode only**. Superb retail breadth (Walmart, Advance Auto
  Parts, Tractor Supply, Home Depot) and still fails req 3, and it is three
  times the area of a 5 W mono panel.
- **Coleman / Sunforce 10 W** — same family; Sunforce's own copy says "a
  charge controller is not required for a 10 Watt solar panel… recommended
  for panels greater than 15 Watts." True for a 50 Ah car battery, **false
  for our 7 Ah**: 667 mA into 7 Ah is ~C/10.
- **Coleman / Sunforce 18 W kit (58032 / 58033)** — this one *does* include a
  7 A charge controller and is stocked at Tractor Supply and Home Depot, but
  18 W is outside the band and it is a large amorphous panel. Noted only as
  the brick-and-mortar option if the Amazon route ever closes.
- **Schumacher SP-200, 2.4 W** — the broadest retail of anything here
  (Walmart, Home Depot, Amazon, farm stores; $15–$40 street, $59.99 MSRP) and
  it still fails: **19.38 × 10.25 × 1.38″ for 2.4 W**, "water-resistant" not
  weatherproof, and no charge controller listed among its components.
- **Harbor Freight Thunderbolt 1.5 W maintainer (SKU 64251)** —
  **discontinued**; product page 404s and it no longer appears in HF's own
  solar search results.
- **Battery Tender solar line generally** — best warranty in the category
  (5 yr) and the best chance of a customer finding one in an auto-parts
  store, but **every panel in it is sold out on batterytender.com** as of
  2026-08-20 (5 W $74.95, 5 W handlebar $89.95, 17 W $134.95, 35 W $179.95)
  and the 10 W is gone entirely. Can't spec a part the maker isn't shipping.

##### If a sub-5 W or unregulated panel is ever wanted anyway

Add one inline controller at the **battery** end (see "Remote panel
placement" above). In stock as of 2026-08-20:

- Battery Tender Solar Charge Controller, SKU 400-0365-BT — **$19.95**
- Battery Tender 5–45 W Automatic Solar Controller, SKU 021-1162 — **$34.95**;
  3 A max out, 32 V max in, 3-stage, AGM/GEL/SLA/flooded/lithium. Setpoints
  not published; the maker's own pages disagree on 1-yr vs 5-yr warranty.
- Harbor Freight Thunderbolt 100 W Solar Charge Regulator — **$14.99**

**One trap, from a verified buyer of the ECO-WORTHY kit:** a panel with a
built-in controller **will not drive a second controller in series** — the two
confuse each other and the panel stops passing current. Pick exactly one
regulator in the chain, either in the panel or inline, never both.

##### Cabling notes for the buried run

All qualifying candidates terminate in **SAE**, so the SAE joint is the
natural splice point for the buried extension, and SAE extension leads are a
stock item. Verified stock lead lengths: SUNER POWER 9.8 ft (longest),
Harbor Freight 8 ft, ECO-WORTHY 2 m (~6.6 ft) — all short enough that a
remote panel needs an extension in every case. Two field reports worth
having: an ECO-WORTHY buyer added 25 ft of 18 AWG speaker wire with no
trouble (consistent with the wire table above at ~0.6 A), and a Renogy buyer
notes none of the supplied leads are fused — **put an inline fuse at the
battery end** of any permanently-installed ring-terminal lead.

Round-2 sources (all checked 2026-08-20):

- Harbor Freight 70830 listing (price, IP65, 600 mA, 24 V Voc, 8 ft cable,
  90-day warranty): <https://www.harborfreight.com/10-watt-solar-trickle-charger-70830.html>
  — owner's manual, source of the "14.6 VDC Max" rating and the
  fully-charged-battery-only caveat:
  <https://manuals.harborfreight.com/manuals/70000-70999/70830-193175515018.pdf>
  — coupon history: <https://hfpricetracker.com/tools/70830> and
  <https://go.harborfreight.com/coupons/2026/05/184727-70830/>
  — HF solar line-up (proves the 1.5 W is gone and the 10 W is In-Store Only):
  <https://www.harborfreight.com/search?q=solar+battery+charger>
- SUNER POWER 5 W Pro: <https://www.amazon.com/SUNER-POWER-Waterproof-Maintainer-UltraSmart/dp/B0DRFGBX5J>
  and <https://sunerpower.com/products/bc-5w-solar-battery-charger-pro>
- SUNER POWER 10 W: <https://www.amazon.com/SUNER-POWER-Waterproof-Battery-Maintainer/dp/B07XNZZHK5>
  — maker's 10 W page (3 m cable, tubular mount, 12-mo warranty):
  <https://sunerpower.com/products/12v-waterproof-solar-battery-trickle-charger-maintainer-10-watts-solar-panel-built-in-intelligent-mppt-solar-charge-controller-tubula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>
- POWOXI 7.5 W: <https://www.amazon.com/Battery-Portable-Waterproof-Maintainer-conversion/dp/B07JLWFPX6>
- ECO-WORTHY 10 W kit, now unavailable: <https://www.amazon.com/ECO-WORTHY-Controller-Maintainer-Waterproof-Adjustable/dp/B0CSMX7PTL>
- ECO-WORTHY 10 W blocking-diode model, in stock: <https://www.amazon.com/ECO-WORTHY-Portable-Backup-Alligator-Adapter/dp/B017K6PH1S>
- Renogy 10 W on Amazon (fabric panel, unregulated per review): <https://www.amazon.com/Renogy-Solar-Battery-Maintainer-Trickle/dp/B07QBY7626>
- Renogy RSP10TC, Unavailable: <https://www.renogy.com/products/10w-solar-battery-trickle-charger-maintainer>
- Battery Tender solar collection (all panels sold out; controller prices):
  <https://www.batterytender.com/collections/solar-panels>
  — 021-1164 10 W, discontinued: <https://www.amazon.com/Battery-Tender-021-1164-Maintainer-Microprocessor/dp/B004Q86JJ8>
  — 021-1162 5–45 W controller: <https://www.batterytender.com/products/battery-tender%C2%AE-5-45w-automatic-solar-controller>
  — 021-1173 17 W (dimensions, 5-yr warranty): <https://www.batterytender.com/products/battery-tender%C2%AE-12v-17-watt-mountable-solar-battery-charger>
- ACOPOWER 5 W HY005-12M (bare panel, dimensions, warranties): <https://www.acopower.com/products/hy005-12m>
- Coleman/Sunforce 6 W 58022: <https://www.amazon.com/Sunforce-58022-Coleman-Battery-Trickle/dp/B004RCR0ZU>
  and <https://shop.advanceautoparts.com/p/coleman-6-watt-12-volt-solar-battery-trickle-charger-58022/10645131-P>
- Coleman/Sunforce 10 W ("no controller needed under 15 W"): <https://www.cabelas.com/p/coleman-10w-solar-battery-trickle-charger-and-maintainer>
- Coleman/Sunforce 18 W kit with 7 A controller: <https://sunforceproducts.com/renewable-energy-products-wind-solar-sunforce/coleman-solar-products/18-watt-12-volt-solar-battery-charger-kit/>
  and <https://www.tractorsupply.com/tsc/product/coleman-18-watt-12v-solar-battery-charger-kit>
- Schumacher SP-200 2.4 W: <https://www.schumacherelectric.com/products/2-4w-solar-battery-maintainer/>
  and <https://www.amazon.com/Schumacher-SP-200-Solar-Battery-Maintainer/dp/B004ZC3TFC>
- Harbor Freight 1.5 W maintainer, now 404: <https://www.harborfreight.com/15-watt-solar-battery-maintainer-64251.html>

---

### Enclosure — 🔶 open

An enclosure for the electronics, with **glanceable status on the outside** —
a walker-by can tell the thermometer is working and the battery is healthy
without opening anything or pulling up the dashboard (which carries the same
info in full).

- **Working indicator**: a slow heartbeat blink (alive + temperature loop
  running). A brief blink every few seconds costs ~nothing from the power
  budget; a solid-on LED would be one of the larger loads — don't.
- **Battery indicator**: state shown simply — e.g. green blink = charging /
  good, red = low. 🔶 Open: one bi-color LED vs two, thresholds (tie to the
  same voltage measurement the dashboard logs).
- Must be readable in daylight (high-brightness LED or light pipe) yet not
  glaring at night in a garden.
- Enclosure itself: outdoor-rated (IP65-ish), gasketed cable entries
  (battery, actuator, sensor, panel SAE, button, servo), and the TMP117
  mounted *outside* the box airflow-wise — electronics self-heating must
  not touch the reading (see Temperature sensor).
- 🔶 Open: off-the-shelf gasketed box vs printed; mounting on/in the
  sculpture base.

---

## Firmware

### Homing cycle and position feedback — required

**On reset the CPU runs a homing cycle** before displaying anything.

Position feedback — two mechanisms, both on the actuator:

- **Encoder: a reed switch** in the actuator. Two wires → one ESP32 input
  pin with a pull-up resistor. Position is relative: count pulses in
  firmware (debounced) from the home reference.
- **End stops: internal limit switches, sensed by motor current.** The
  limits are electrical switches inside the motor with no separate signal
  wires. Commanding the motor **inward** (retract, shortest length) until it
  reaches the stop opens the internal switch — **motor current drops to
  zero, and that current drop IS the stop detection**. The switch only cuts
  drive in the stop's direction: commanding **out** again always moves; the
  actuator never drives backwards through a stop. Motion is strictly in/out.

Homing sequence: drive in → watch motor current → current ≈ 0 means the
inner stop → that's home; zero the reed-switch count there, then move out to
the position for the current temperature.

The actuator is the Joyce QS11940 (measured dimensions and mounting in
FABRICATION.md). 🔶 Open: reed-switch pulses per inch of stroke — measure
during bring-up; it sets the position resolution the calibration can hold.

**Consequence for the motor-driver choice: current sensing is a hard
requirement** (see Motor drivers) — it's the only way to see the stops.

### Calibration — required

Provision for calibrating actuator movement against the actual engraved
scale on the built mechanism — the sim's temp→extension mapping is the
starting spec, but the real linkage/scale will not match it perfectly.

- **Done from a phone**: a web UI served by the ESP32 (lives in `src/web/`).
  Jog the actuator, mark where the indicator actually sits on the engraved
  scale, store the correction persistently (NVS).
- 🔶 Open: calibration model — two-point (offset+gain over the linear
  temp→extension map) vs a multi-point table interpolated along the scale.
  The scale is deliberately non-linear in *arc length*, but temp→extension
  is linear by design, so two-point may suffice; multi-point is the fallback
  if the built mechanism deviates.

### Power management

**Operating model (owner, 2026-08-20): wake every 30 s, run ~1 s, deep-sleep
the rest** — temperature doesn't change fast enough to justify staying up.
Read the TMP117, move the motor if the reading crossed a 1° step, back to
sleep. WiFi comes up only in service windows (button wake) and scheduled
fetches — see the Solar energy budget for the numbers (~0.5 Wh/day) and the
reachability consequence. Day/night distinction stops mattering at this
duty cycle.

**RESOLVED 2026-08-20 — comprehensive power analysis, WiFi ON.** The owner
asked for a realistic number at reduced CPU speed with WiFi kept open, and
directed: don't design around power-saving heroics. Official Espressif
measurements for the ESP32-S3 in Wi-Fi scenarios
(<https://docs.espressif.com/projects/esp-idf/en/stable/esp32s3/api-guides/low-power-mode/low-power-mode-wifi.html>):

| Mode (WiFi connected & reachable) | Average current @3.3 V |
|---|---|
| Modem sleep, DFS ON (CPU auto-downclocks when idle) | **19.5–20.7 mA** (DTIM10–1) |
| Modem sleep, DFS OFF (CPU pegged at 160 MHz) | 38.2–40.1 mA |
| Auto light-sleep, still associated (wakes per DTIM beacon) | **0.93–2.45 mA** |
| Deep sleep (WiFi disconnected) | 6.9 µA |

Readings:

- **DFS (dynamic frequency scaling) IS the "run the CPU slower" idea**, done
  automatically by ESP-IDF: enabling it halves consumption vs a pegged CPU
  (20 mA vs 39 mA) with WiFi fully open. Standalone CPU-frequency baselines
  agree: ~20–31 mA at 80 MHz vs ~30–50 mA at 240 MHz
  (<https://www.luisllamas.es/en/esp32-power-consumption/>,
  <https://www.makerguides.com/measuring-esp32-power-consumption-with-power-profiler-kit-ii/>).
- **Design number: WiFi always on, modem sleep + DFS → ~20 mA ≈ 66 mW ≈
  1.6 Wh/day at the 3.3 V rail, call it ~2 Wh/day from the battery** with
  buck losses. Motor bursts add <0.5 Wh/day. Total **≤ 2.5 Wh/day** with
  zero sleep heroics and the dashboard reachable 24/7.
- Auto light-sleep is a free 10× on top (1–2.5 mA, *still associated and
  mDNS-reachable*, latency = DTIM interval) if ever wanted — but it is not
  needed for the panel to balance, which is the point.
- 💡 Parked (owner, undecided): a double-button-press "enter WiFi mode"
  gesture. Unnecessary for power at these numbers — WiFi can simply stay
  on — but kept as an idea if reachability is ever restricted on purpose.

Earlier framings, kept for the record (both superseded by the analysis
above — the first assumed the MCU stays on all day at devkit-class draw,
the second was a 30-s wake/sleep duty-cycle model the owner set before
directing "let's not even worry about power saving mode"):

- **Explore the DevKitC's low-power modes.** The ESP32 chip deep-sleeps at
  ~10 µA, but the DevKitC board carries a USB bridge and LDO that draw
  quiescent current regardless — measure what the *board* actually pulls in
  deep sleep before counting on it. If it's too thirsty, options: light
  sleep with periodic wake, or cutting the board's power upstream on a
  timer/RTC. (The production S3 board escapes this — see MCU.)
- Evening entry into low power; wake at least often enough to keep the
  displayed temperature honest overnight (it's a thermometer — 🔶 decide the
  night refresh interval).

### Dashboard

The web UI serves a statistics dashboard:

- Current temperature, today's high and low so far (from the TMP117 log),
  and **today's forecast** pulled from an online provider (🔶 open: which —
  NWS/weather.gov is free and keyless for US locations,
  <https://www.weather.gov/documentation/services-web-api>; OpenWeatherMap
  etc. need keys). Same data feeds the walk-up forecast mode.
- **Battery health**: live battery voltage and charge state (owner said
  "charge date" — assumed charge rate/state, 🔶 confirm), plus a **rolling
  30-day log of battery voltage cycling**, so the daily charge/discharge
  curve shows at a glance whether the charge controller is doing its job.
- Implications: a voltage divider from the battery bus into an ESP32 ADC
  (scaled for 24 V max; calibrate the divider — ESP32 ADC is sloppy), and
  ~30 days of samples persisted in flash (LittleFS; e.g. 5-min samples ≈
  8.6k points — trivial). Consider an INA226-style monitor if charge
  *current* turns out to matter for judging the controller.

### OTA updates — required

Firmware updates over WiFi — the ESP32 lives inside an outdoor sculpture;
no USB cable to reflash. Standard ESP32 dual-partition OTA (upload via the
web UI or push over the LAN), with rollback to the previous partition if the
new image fails to boot.

### Network / discovery — required

- **mDNS** so a phone finds the thermometer by name (e.g.
  `thermometer.local`) on the local LAN.
- **AP-mode fallback**: no configured WiFi or LAN unreachable → the ESP32
  runs its own access point; the phone joins it and reaches the same web UI
  (mDNS in AP mode too, plus captive-portal redirect is the usual trick).
- Same web server serves calibration and, later, the forecast-mode
  configuration; WiFi credentials get provisioned through the AP-mode page.

---

## Features

### Walk-up forecast mode — 💡 proposed 2026-08-20

A walker presses a button and the thermometer displays today's forecast high
and low, then returns to the current temperature.

**Mode dial:** while the indicator is traveling, the viewer needs to know
*what* it is moving to. A **hobby servo** sweeps a small dial between three
engraved positions — **HIGH / CURRENT / LOW** — pointing at the one the
indicator is currently heading to (or resting on).

Proposed sequence on button press: servo → HIGH, actuator drives to the
forecast high, dwell; servo → LOW, drive to the forecast low, dwell;
servo → CURRENT, return to live temperature. (Order/dwell times TBD.)

Hardware/firmware implications:

- **Button**: weatherproof momentary switch, ESP32 GPIO, debounced;
  ignore/queue presses while a cycle is already running.
- **Servo**: standard hobby servo, 50 Hz PWM from ESP32 LEDC, runs on the
  5 V rail — adds a peak-current blip to the buck budget. Outdoor-rated or
  housed; consider powering it down between moves to save idle draw and
  avoid hunting.
- **Forecast source**: needs today's high/low. ESP32 has WiFi — a weather
  API is the obvious route, but requires internet at the garden. Leading
  candidate: NWS/weather.gov API — free, no API key, US-only
  (<https://www.weather.gov/documentation/services-web-api>). 🔶 Open:
  connectivity (home WiFi reach? cellular? fall back to recorded
  today's-min/max from the TMP117 if offline), and a keyed provider
  (OpenWeatherMap etc.) for non-US customers.
- The temp→extension mapping already handles arbitrary targets; this is a
  setpoint sequencer on top, not a new mapping.

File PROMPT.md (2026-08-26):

GOAL
Rebuild the 3D-printable benchtop model of the kineticThermometer serpentine
mechanism natively in Autodesk Fusion 360, through the Fusion MCP connection, as
separate components with joints, so the assembly actually articulates when the
shuttle is dragged. The geometry is already fully solved and verified; do not
re-derive it — transcribe it.

WHERE EVERYTHING LIVES (read-only; do not edit the repo, no git operations)
- Repo: the kineticThermometer checkout this file sits in, branch 3dfab-level.
  All paths below are relative to the repo root.
- tools/print3d.py — the generator. Its constants block and docstring are the
  spec. print/ is committed, so you do NOT need to rerun it; if you want to
  (python3 tools/print3d.py), it needs pip installs: numpy shapely trimesh
  mapbox_earcut, plus tools/explore_designs.py beside it.
- print/fusion-data.json — exact numbers in Fusion-ready mm: mount XY, per-part
  local hole coordinates, level z table, post/sleeve lengths per joint, screw
  table, plate bounds, and Q/R/B/C/P/D pose checkpoints at ext0/mid/ext15.5.
  This file is your primary data source.
- print/PRINT.md — bill of materials, screw/washer table, assembly order.
- print/*.stl — the verified geometry. assembly.stl is everything placed at
  mid-stroke; use it as a visual cross-check (insert as mesh if helpful).

CONNECT FIRST
Use the `fusion` MCP registration — Autodesk's built-in Fusion MCP Server at
http://127.0.0.1:27182/mcp (enabled in Fusion Preferences ▸ General ▸ API; its
fusion_mcp_execute tool runs Python inside Fusion). That is the ONLY Fusion MCP
server on these machines; anything mentioning "AutodeskFusionMCP" or port 8765
is stale — it was removed 2026-08-25. Before declaring Fusion unreachable, run
~/claude-code-fusion-mcp-check/check.sh and follow exactly what it prints;
if it exits 0 but this session lacks the tools, the session is stale — restart
it (MCP servers attach at session start). Create a NEW design document (suggest name
"kineticThermometer-bench-3dfab"), units mm. Never modify the owner's existing
designs (notably "Joyce QS11940 Linear Actuator").

COORDINATES
All numbers are model mm, y already flipped to CAD convention (matches the
repo's Points DXF), z up from the back plate bottom. Scale is 5 mm per real
inch. Sketch parts on XY, extrude +Z.

COMPONENTS TO CREATE (all flat extrusions; no lofts, no booleans needed beyond
holes/pockets)
1. backplate — rectangle from plate_bounds_model_mm (x -104.511..81.928,
   y -24.148..139.587), 4 thick; Ø3.4 through-holes at the four mounts
   (mounts_model_mm: O2, O4, O6, ANCH); four Ø10×6 feet under the corners,
   inset 7 from each edge. The raised path ridge (1.2 wide, 1.2 tall along the
   temperature curve) is cosmetic — either skip it, or pull the 141-point Q
   path by running, from the repo root:
     python3 -c "import sys; sys.path.insert(0,'tools');
     from print3d import *; m=Model(GEO);
     print('\n'.join(f'{p[0]:.3f},{p[1]:.3f}' for p in m.pt['Q']))"
   and loft a 1.2×1.2 profile along a fitted spline on the plate top.
2. crank — capsule 8 wide, axis from (0,0) to (63.075,0), holes Ø3.4 at 0 /
   56.85 (B) / 63.075 (R); 4 thick, with two flush-head pockets Ø6.5×2 deep:
   at B opening UP (+Z face), at R opening DOWN. (The STL is two 2mm laminates
   only because the printing pipeline cannot cut counterbores; in Fusion just
   cut the two counterbores in a single 4mm body.)
3. plate1 — hollow triangle: 8-wide capsules along edges B(0,0)→C(38.852,0),
   C→P(17.5,-56.5), P→B; Ø3.4 at all three points; 4 thick. Do NOT fill the
   triangle — filled plates collide with the posts (proven).
4. rocker1 — capsule (0,0)→(35.071,0), Ø3.4 both ends, 4 thick.
5. plate2 — hollow triangle P(0,0)→D(29.5,0)→Q(99.996,-65.744)→P, same recipe.
6. rocker2 — capsule (0,0)→(70,0), Ø3.4 both ends, 4 thick.
7. bar — capsule 12 wide, 4 thick, axis (0,0)→(197.6,0); Ø3.4 pivot at origin;
   slot 5.4 wide, centerline from x=120.0 to x=197.5 (rounded ends). The slot
   ends are the stroke stops — exact, do not lengthen.
8. shuttle — boss Ø5×4.4 below a Ø16 flange, total height 6.0, Ø3.4 through;
   hex recess across-flats 5.8, depth 4.5, in the top face.
9. ring — flat 2.5 thick: hub Ø7 with Ø3.4 hole, ring band ID16/OD20 centered
   on the hub, three 1.6-wide spokes hub→band.
10. posts — Ø8 tubes, Ø3.4 bore: lengths 6 (O4), 30 (O2), 42 (ANCH), 54 (O6),
    one each (post_by_ground in the json).
11. sleeves — Ø6.5 tubes, Ø3.4 bore: 8 long ×4 (joints B, C, D, R), 44 long ×1
    (joint P) (sleeve_by_joint in the json).
Screws/nuts/washers: optional; model as cylinders or omit. The screw table in
PRINT.md is for the physical build, not the CAD.

Z-STACK (link bottom heights; link tops +4)
level 0 rocker1 z=10 · 1 plate1 z=22 · 2 crank z=34 · 3 bar z=46 ·
4 rocker2 z=58 · 5 plate2 z=70. Plate occupies z 0..4. Posts stand plate top →
their link bottom; sleeves span lower-link top → upper-link bottom at each
joint. Ring sits on plate2's top (z=74); shuttle rides the bar top (z=50).

PLACEMENT AT MID-STROKE (then let joints govern)
Use pose_checkpoints['mid'] from the json. Each part's local frame: first hole
at the listed world point, local +X aimed at the second: crank O2→B, plate1
B→C, rocker1 O4→C, plate2 P→D, rocker2 O6→D, bar ANCH→R. Mounts are fixed at
mounts_model_mm. All rotations are about Z only.

JOINTS (target: exactly 1 degree of freedom)
- Ground the backplate. Rigid-join each post to the backplate at its mount,
  each sleeve may be rigid to either of its two links, ring rigid to plate2 at
  Q.
- Revolute (Z axis) at: O2 backplate↔crank, O4 backplate↔rocker1,
  O6 backplate↔rocker2, ANCH backplate↔bar, B crank↔plate1,
  C plate1↔rocker1, P plate1↔plate2, D plate2↔rocker2.
- Shuttle: revolute shuttle↔crank at R, plus a slider/pin-slot shuttle↔bar
  along the bar's slot axis. If Fusion fights the closed-loop constraint
  system, the pin-slot (rotation + translation in one joint) between shuttle
  and bar is the robust choice. Optionally set joint limits to the slot span
  (120..197.5 from the pivot) — that is the actuator excursion 0..15.5″.

VERIFY (do all three, report results)
1. Drag the shuttle end to end: the mechanism must articulate smoothly and
   stop at both slot ends. If a joint pops, check the placement frame of that
   part against pose_checkpoints['mid'].
2. Measure the ring center (Q) at the two extremes and mid: expected model-mm
   XY — ext0: (-6.909, 110.456), mid: (70.625, 129.587),
   ext15.5: (4.972, 99.501). Tolerance ~0.1mm.
3. Run Fusion's Interference check at ext0, mid, ext15.5. The design was
   cleared per-pose in Python (tightest hardware gap 7.1mm; link planes are
   12mm apart with 8mm air) — any interference means a transcription error,
   not a design error.
Take a screenshot of the finished assembly for the owner.

CAUTIONS
- The hole/slot dimensions carry 3D-print clearances (Ø3.4 for M3, slot 5.4
  over a Ø5 boss, pockets Ø6.5). Keep them exactly — they are the spec.
- The STLs stack sections with 0.1mm overlaps (slicer-friendly EPS); when
  modeling natively, make faces exactly coplanar instead.
- Level order, hollow plates, the trimmed bar tip, and the flush pockets at
  B/R are all load-bearing results of a collision search — do not "improve"
  any of them.
- Ask the owner before any destructive Fusion operation (closing unsaved
  docs, overwriting designs). Do not commit, push, or edit the repo.

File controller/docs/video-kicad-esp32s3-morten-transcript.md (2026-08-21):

# Transcript — "ESP32-S3 Simple TestBoard designed in KiCad"

Source: <https://www.youtube.com/watch?v=Z5AQMZh3qXw> — *made by morten*, uploaded
2026-08-21, 2:29:31. Audio pulled with `yt-dlp`, transcribed 2026-08-21 with
OpenAI Whisper `large-v3-turbo` (CUDA), then blocked into ~45-second paragraphs
with the timestamp of each block's first segment.

**Machine transcript — not proofread.** Whisper mangles part numbers and repeats
filler ("and and and", "by by by") during silent stretches where morten is
clicking rather than talking. Known misreadings: "KiCat" = KiCad, "room module"
= WROOM module, "LGO"/"LTO" = LDO, "quick" = Qwiic, "screw tunnel" = screw
terminal, "school" = screw, "spark phone" = SparkFun, "via/VR/VS/view/severe" =
via, "source free/smooth" = RGB colour names, "freedom model" = 3D model,
"gerber" is usually right. 1:21:25–1:22:30 and 2:21:25 are largely garbled —
the board is silent there.

The digested findings live in
[video-kicad-esp32s3-morten.md](video-kicad-esp32s3-morten.md); the decisions
they feed live in [../DESIGN.md](../DESIGN.md).

---

[0:00:00] Hi guys, I'm working on a small and very simple ESP32-S3 testboard in KiCat and it's based on the room module. This video will go through the whole process from making and designing the schematic to routing and ordering the PCB. The main features for this board are an ESP32-S3 room module with 8 megabytes of flash, a button for reset, user button, user RGB LED, an expansion header, programming header and a power LED on the 3 volt rail. For the mechanical size of things we will have four 3.2 millimeter mounting holes, the size will be 45 by 45 millimeters and it will be a four layer board design. And just before we start the project I would like to thank PCBWay for making this video

[0:00:51] possible. Remember that there are a large section on PCBWay.com where you can find a lot of projects and inspiration from other makers. If you find a particular project interesting then you can often directly order the PCB at PCBWay. You'll find my affiliate link in the video description of this video, please use it and thereby support the channel. So remember to visit PCBWay.com. So let's dig into it. So here we are in the KiCat project manager. I already created this project called ESP32-S3-Small and we have both here a schematic file and a PCB file. So let's get started doing the schematic design. Just double click here on the schematic file and here we have a blank canvas. So the first thing I normally

[0:01:42] do is to go into page settings to identify what I'm actually doing, which project I'm working on and let's fill in the date. We just click on these arrows here. Revision 1.0. The tile that's an ESP32-S3-Small testboard company. That's the YouTube channel name made by Morten and I think this is good for now. And then you see down here, this has been automatically filled in and we are ready to start the design.

[0:02:33] So we are going to use the ESP32-S3 room module. So let's get started placing some of the parts we need. So we go to place symbols and we will search for an ESP32-S3 and we have different models to choose from. And we are just loading some of the libraries. I have different models here. Let's see what we can find. Yeah, I think this one. This is one I made in a previous project.

[0:03:23] You can see the way the pins are organized here. It's a bit messy. And also for this one for another room module. So I re-routed some of the pins where they are placed in order to get a better overview. But you can of course download this project on my GitHub. And there is also the libraries that are being used in this project. So let's place the module here. And zoom in. So the first thing we would like to place is give some power and some decoupling capacitors to this module. So let's place power symbols. Let's press P.

[0:04:14] And we will use a 3.3 volt net. And for the crowd pins. Something like this. Something like this. And let's place some ground. And I would like the ground symbol to be a bit closer or the text for the ground to be a bit closer there.

[0:05:00] And we need some decoupling capacitors on the 3.3 volt net. Place symbols. And let's look for a capacitor. And I would like to use this small symbol. And normally I place a 10u. There. And of course a 100 nano. And we just press Ctrl D for duplicate.

[0:05:50] And then we edit the text here. 100 nano. And then we can just duplicate the ground symbol here. Mark it and press Ctrl D. There we should maybe have this a bit further out. Then we can take the wire along. Like that. So now we have C1 and C2.

[0:06:38] We have ground connected. Then we have the enable signal. And that's one of the signals that we are going to use from the programmer. And we would also like to have a button here. So we can actually reset the module. So the enable signal here is actually the reset pin as well. So let's place a wire here. And we would like to have a small button here. Where we can push and then reset the ESP32 S3. And we do that by connecting this pin to ground. And we would like to have a switch.

[0:07:24] And that should just be a single. Let's see. So symbol for push button. I think this is the one. And then we will connect that to ground. And we can remove this small stop here. Like that.

[0:08:12] But of course we need. To have a pull up pin. Or pull up resistor. And a capacitor here. In order to time the correct. Pulse for the reset. It needs to charge a capacitor. And that will be done through a 10 kilo ohm resistor. So let's find a resistor. And we can put that around here. We will take the 3.3 volt net. And just copy that. And we will need a capacitor as well.

[0:09:13] To make this RC filter. And that will be a 1 micro. And we will change this to a 10 kilo ohm resistor. I think that's it. And when we have this button here. And we will have our finger. Getting close to the enable signal. Then we will also protect it. By using a small ESD diode. Place symbol.

[0:10:00] And there will be an ESD. I have it already here. It will protect the 3.3 volt line. And we can just remove. Yeah. We will just keep the text as is. Like that. Maybe we should just move this down a tiny bit. And we can move this as one as well. I like there's a bit of symmetry in it.

[0:10:45] It's easier to read the schematic then. Like that. So now we have the most important things. For the ESP32 room module. There are some things we need to take care of. When we look at the pins. On the ESP32. There are some strapping pins. So I have this text already prepared. We can just go through it. Let's copy it. And then we can insert a small text box here. And paste the text in here.

[0:11:41] Something like this. And we can move it up a bit. Like that. So we have to be aware of some of the pins. If we use an ESP32 S3 with embedded RAM. So we need to take care of not using. IO35, IO36 and IO37. They are being used internally. So we can just check it over here. There is a small star here. That says okay. Please have a look on. On these pins. If you are. If you want to have a module with embedded RAM inside.

[0:12:32] But if you don't have a module with that. Then you are free to use these pins. And then you have to be aware of the strapping pins. That's GPIO 0 and 3. And then 45 and 46. So it's easier just to not play with these pins. If you have enough pins. If you are using all the pins. Then you should be aware of how these pins behave. So the only thing that we need to do. Is to put a pull up resistor on GPIO number 3. And normally we just put a 10 kilo resistor on that one. And GPIO 0 is used for the programming.

[0:13:21] Along with the ESP enable signal. And the RX and TX pins. That we are going to fill in on a connector. But a bit more on that later. So let's just connect a 10 kilo ohm resistor. To GPIO 3. I think we can do it like that. I think we can do it like that. Like that. Maybe one. And up there.
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

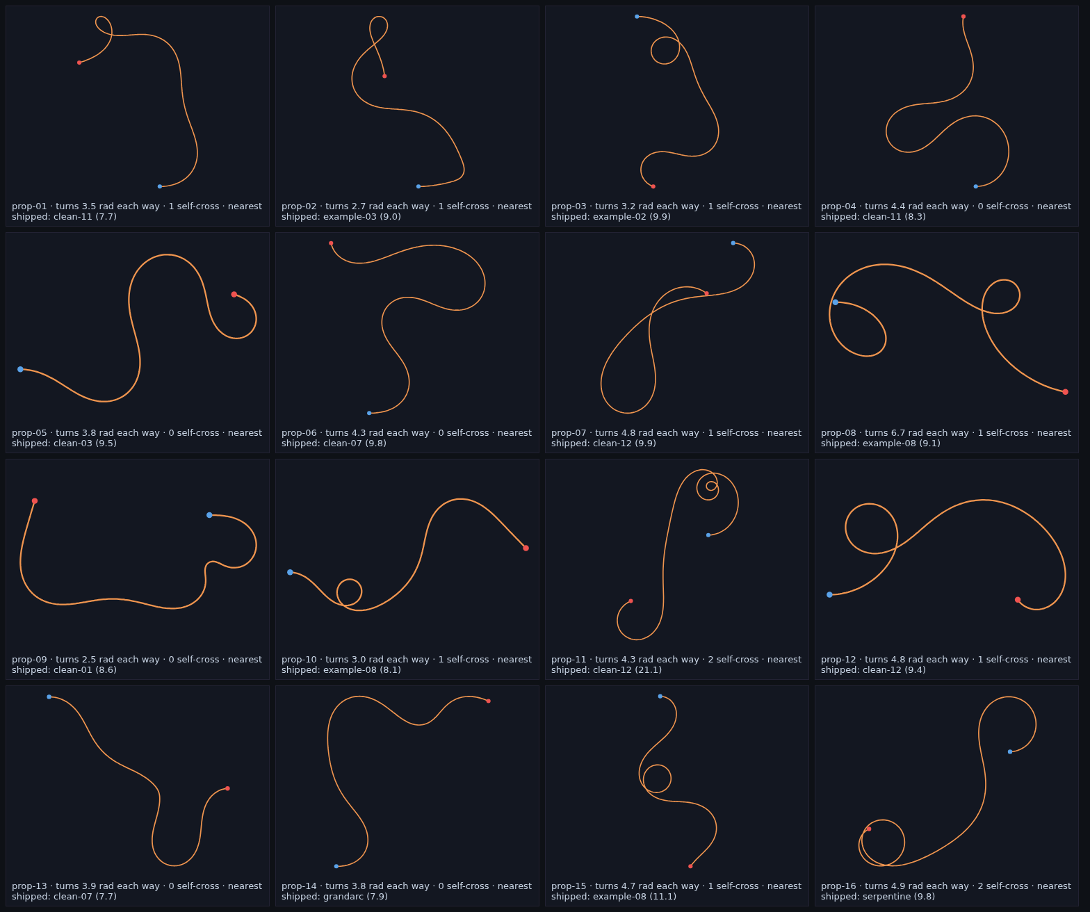
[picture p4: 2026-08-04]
proposals.png

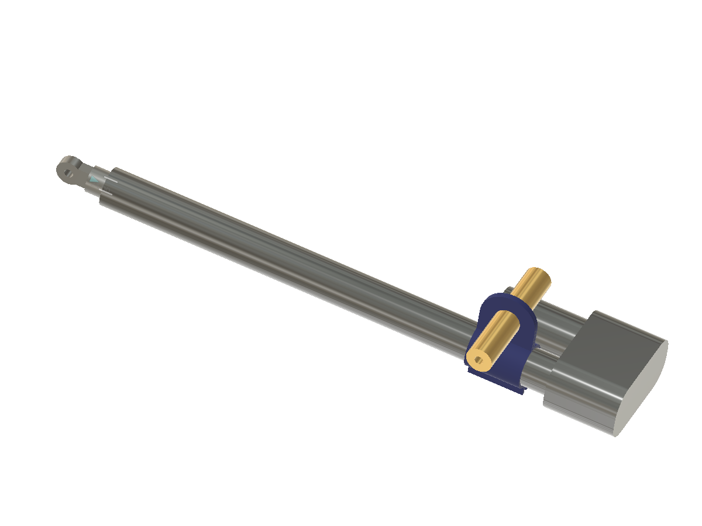
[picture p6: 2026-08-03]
images/joyce-iso.png

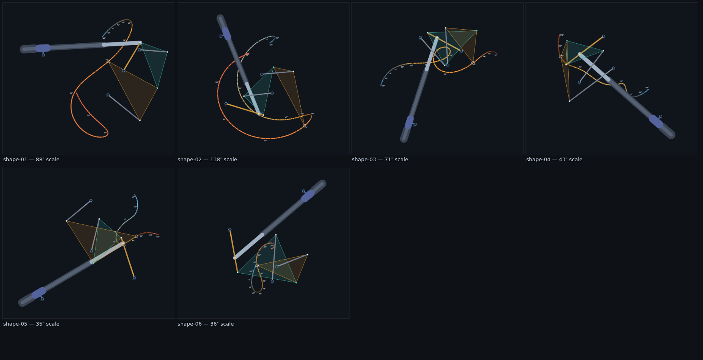
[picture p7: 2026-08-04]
contact-sheet-shape.png

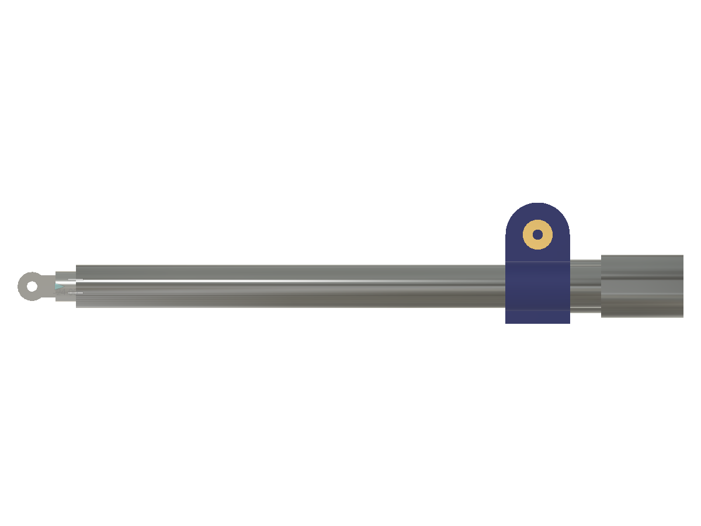
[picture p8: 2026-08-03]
images/joyce-pivot-axis.png

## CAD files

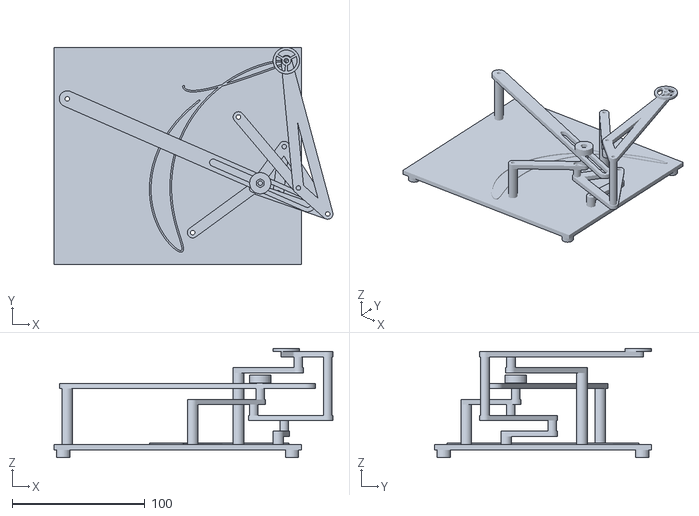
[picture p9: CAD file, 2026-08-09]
print/assembly.stl
210.3 x 163.7 x 82.5

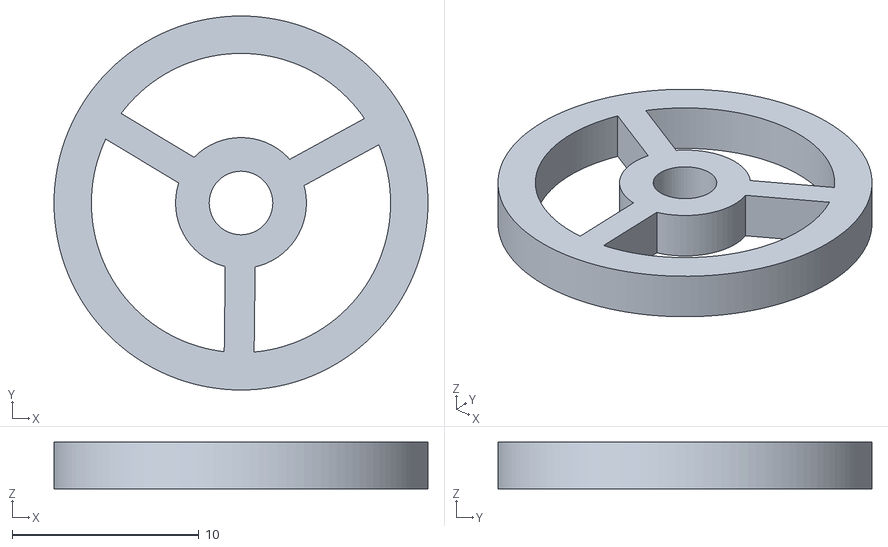
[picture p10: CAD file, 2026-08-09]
print/ring.stl
20.0 x 20.0 x 2.50

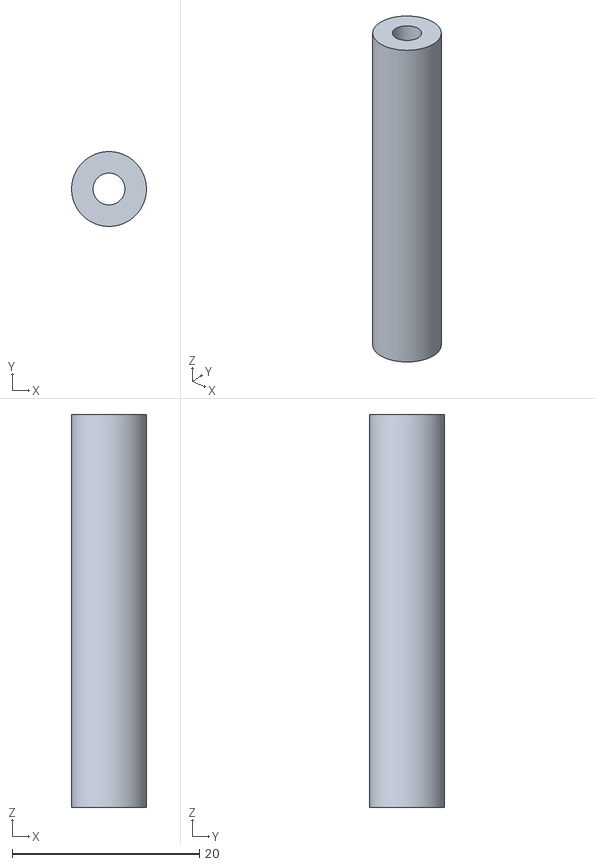
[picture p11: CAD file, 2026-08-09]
print/post_42mm.stl
8.00 x 8.00 x 42.0

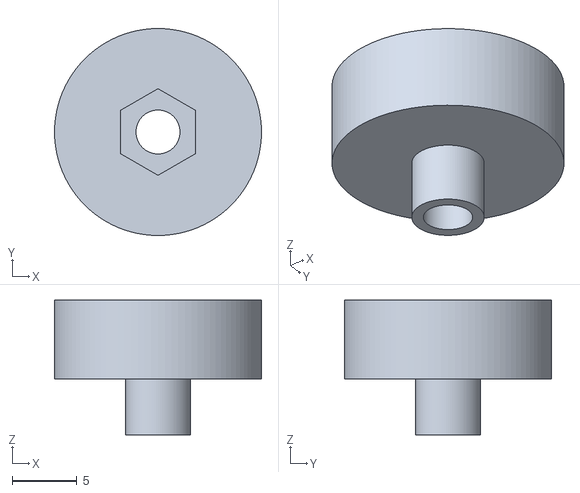
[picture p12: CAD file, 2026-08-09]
print/shuttle.stl
16.0 x 16.0 x 10.4

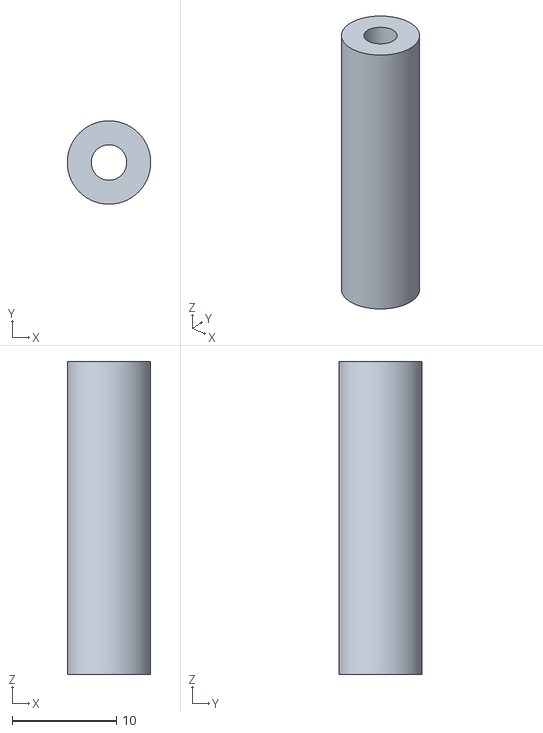
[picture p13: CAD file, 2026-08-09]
print/post_30mm.stl
8.00 x 8.00 x 30.0

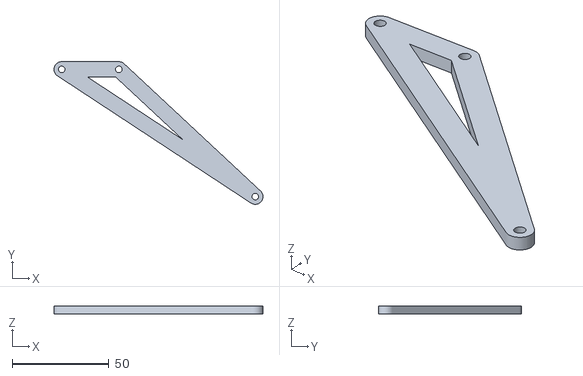
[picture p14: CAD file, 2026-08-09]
print/plate2.stl
108.0 x 73.7 x 4.00

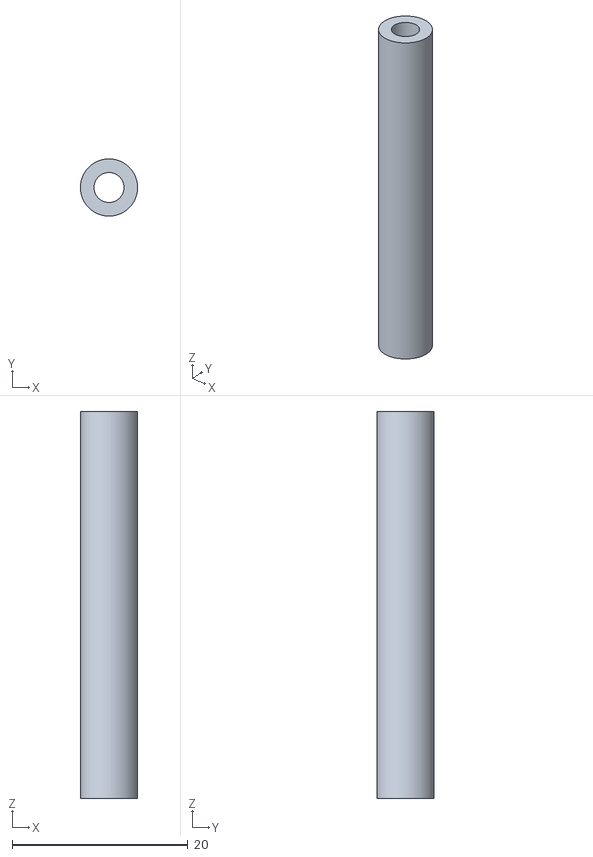
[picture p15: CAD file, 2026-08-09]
print/sleeve_44mm.stl
6.50 x 6.50 x 44.0

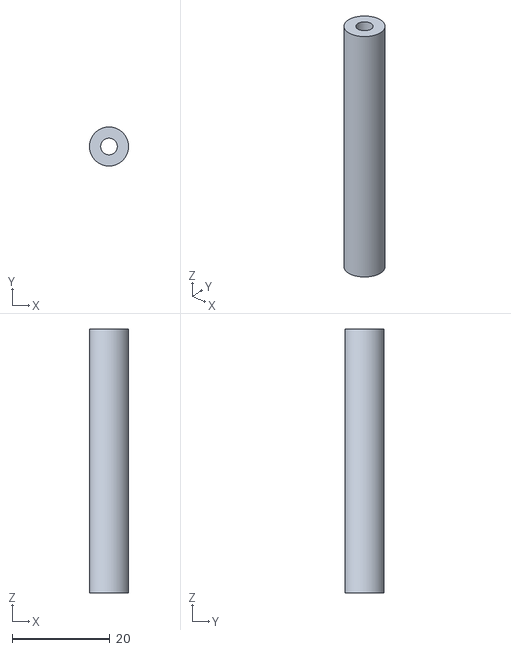
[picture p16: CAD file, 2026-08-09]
print/post_54mm.stl
8.00 x 8.00 x 54.0

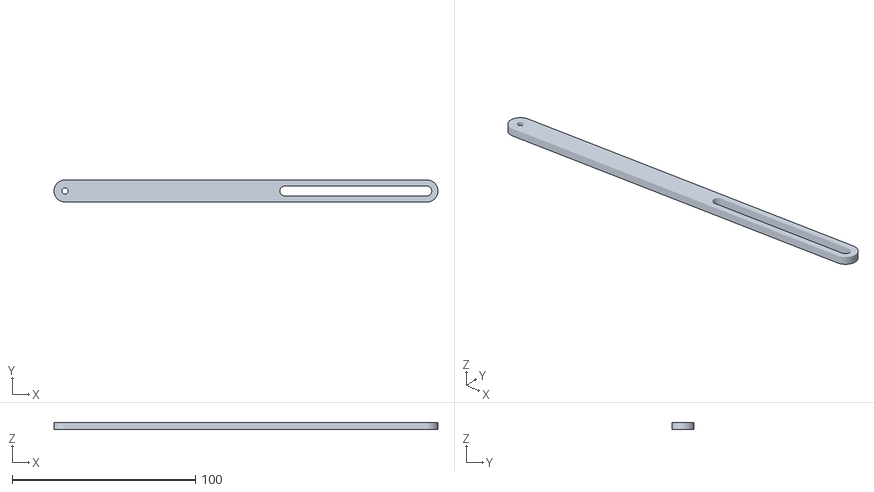
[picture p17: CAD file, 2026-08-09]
print/bar.stl
209.6 x 12.0 x 4.00

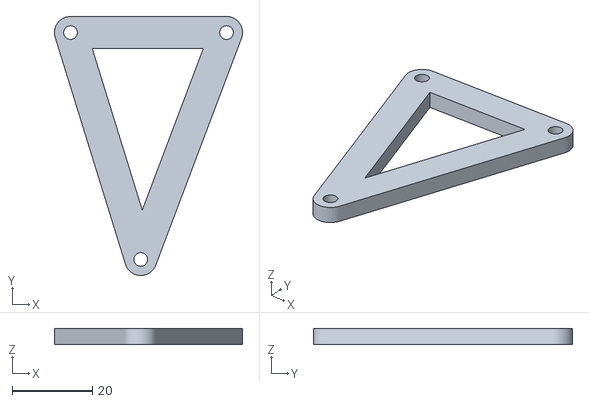
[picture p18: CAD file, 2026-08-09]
print/plate1.stl
46.9 x 64.5 x 4.00

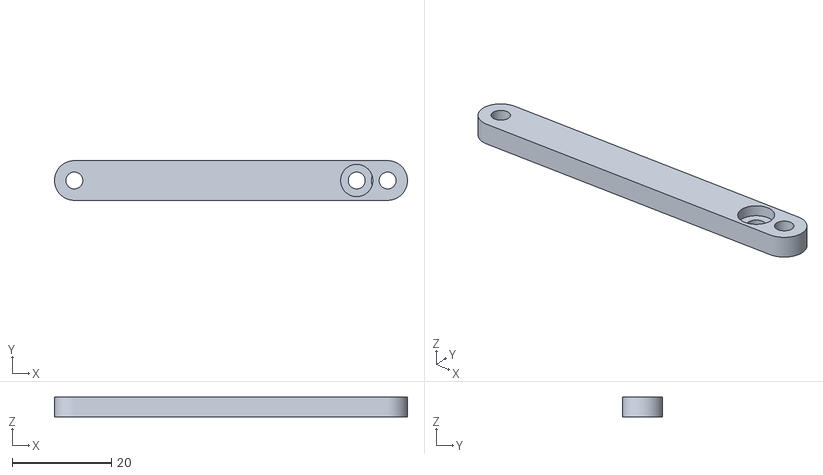
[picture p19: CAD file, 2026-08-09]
print/crank.stl
71.1 x 8.00 x 4.00

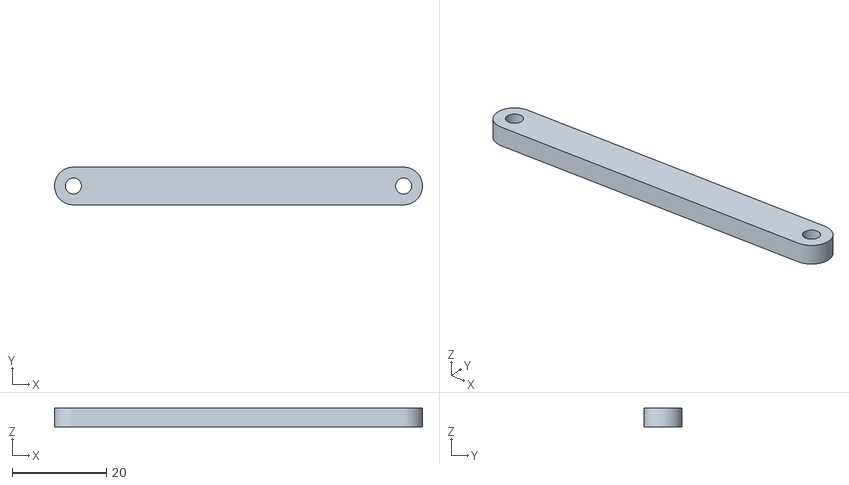
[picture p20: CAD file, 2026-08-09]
print/rocker2.stl
78.0 x 8.00 x 4.00

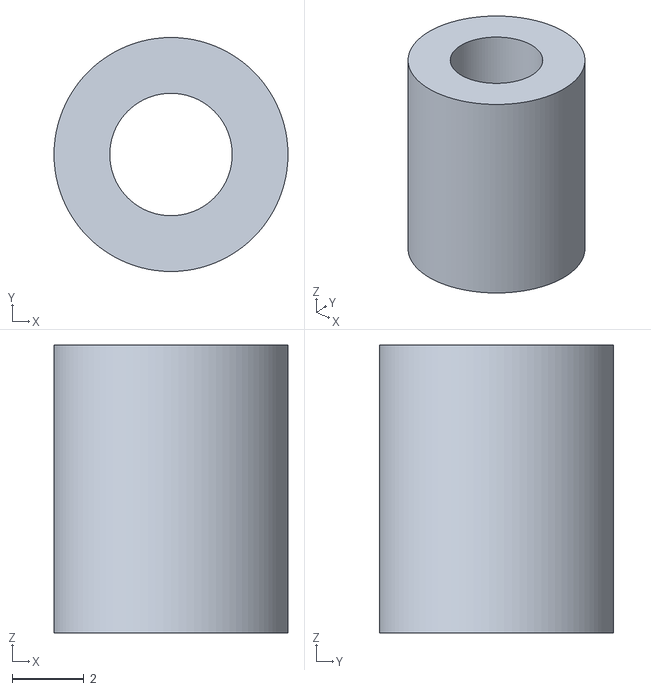
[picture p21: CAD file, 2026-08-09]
print/sleeve_8mm.stl
6.50 x 6.50 x 8.00

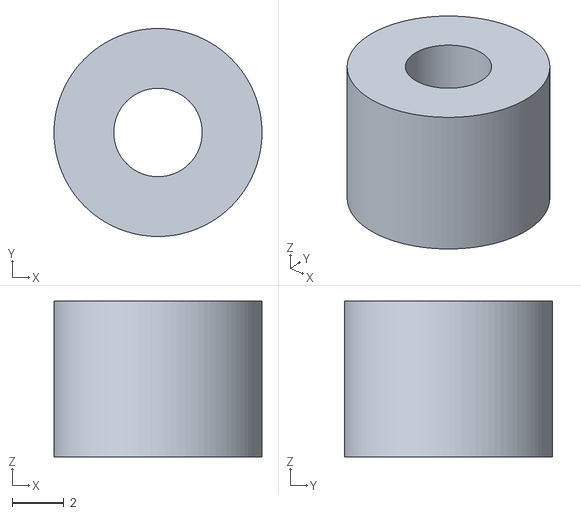
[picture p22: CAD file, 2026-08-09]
print/post_6mm.stl
8.00 x 8.00 x 6.00

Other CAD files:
print/rocker1.stl
print/backplate.stl

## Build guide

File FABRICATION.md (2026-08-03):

# Fabrication notes

Everything a shop needs to cut this piece, plus the measured facts about the
current design. Numbers come from `tools/analyze_geometry.py`; re-run it after
**any** geometry change, because they go stale the moment the preset moves:

```
python3 tools/analyze_geometry.py dump.json     # dump.json = copy(__ct.dump())
```

## Hardware — two selectable actuator types

The simulator's Actuator drive section selects between:

- **Generic pin-to-pin** — retracted length and stroke are editable fields,
  defaulting to **24″ retracted + 18″ stroke = 42″ extended** (the original
  assumed hardware). Old saved designs load as this.
- **Joyce QS11940 (the owner's actual actuator)** — rear mount is a split
  clamp sliding on the tube, pivot pin offset from the tube axis. All
  dimensions below were measured from the owner's Fusion model
  ("Joyce QS11940 Linear Actuator") over the Fusion MCP link on 2026-08-02:

| quantity | value |
|---|---|
| Stroke | **16.000″ exactly** (slider-joint limits in the model) |
| Pivot offset from tube centerline | **2.378″** |
| Clamp position `c0` (pivot → rod pin at full retraction) | adjustable **3.48–24.66″**, as-modeled **23.23″** |
| Rod pin ahead of tube front at retraction | 2.008″ |
| Tube Ø / rod Ø | 2.00″ / 1.378″ |
| Pin holes (clamp pivot AND rod clevis) | **Ø0.472″ (12 mm)** |
| Tube body length (incl. motor pod) / grippable tube | 27.913″ / 24.134″ |
| Clamp width along tube | 2.953″ |

  Driven length is `√((c0+ext)² + 2.378²)` from the clamp pivot to the rod
  pin. The clamp clears the motor pod, so it can traverse the full tube.
  `JOYCE.side` (+1/−1, which side the pivot ear points) is a mounting choice
  still to confirm. Reference views from the Fusion model:
  [images/joyce-iso.png](images/joyce-iso.png),
  [images/joyce-pivot-axis.png](images/joyce-pivot-axis.png).

- Usable slice of the selected stroke is configurable (excursion min/max,
  inches of extension) so the build can stay off the end stops. Currently
  **0–15.5″** on the generic type; the Joyce closes the drive triangle over
  its **full 0–16″** stroke at the as-modeled clamp position (asserted by
  `verify_export.py`).

## Current geometry — Serpentine, owner-tuned

All coordinates inches, origin at **O2** (the bell-crank pivot).

```
rA=12.6151  dA=27.6388  anch=-133.1494°
stage 1: gx=12.9  gy=-6.0  L2=11.3701  L3=7.7705  L4=7.0142  cu=3.5  cv=11.3  s1=-1
stage 2: ox=6.9036  oy=-17.4189  L5=5.9  L6=14.0  cu2=19.9991  cv2=13.1489  s2=-1
```

- **82.5″** of path, from an 18″ stroke.
- Assembles across the whole 0–15.5″ excursion.
- Footprint square-on: **40.7″ × 30.8″** — the path, every swept joint, and
  all four mounts, i.e. the envelope the mechanism actually occupies. At the
  110° default view angle it reads 32.5″ × 43.3″; rotate the view to your
  mounting angle and the box reports the footprint at that angle.

## Open concerns — read before cutting

### 1. O2 fails the mount clearance rule

Every fixed mount must clear the path by **≥2.5″**. Measured:

| mount | clearance | |
|---|---|---|
| O2 (bell-crank pivot) | **2.06″** | under the rule |
| O6 (rocker-2 ground) | 5.28″ | ok |
| ACT (actuator anchor) | 15.77″ | ok |
| O4 (rocker-1 ground) | 16.11″ | ok |

The mount-to-mount crossing rule was dropped by the owner, so mounts may sit
on either side of the path. Clearance still stands, and O2 is short by 0.44″.

### 2. The GENERIC actuator has ~0.25″ of headroom; the Joyce does not have this problem

On the generic type, `dA + rA = 40.25″`, so the drive triangle stops closing
past about **15.75″** of extension. That is why the excursion is 15.5″ and
not 17″.

- The controller must **never** command past 15.5″. Beyond the limit the
  linkage cannot reach a valid pose — the actuator stalls against geometry it
  physically cannot satisfy.
- Re-check this figure if `dA`, `rA`, or the excursion is touched at all.
- On the **Joyce** type at the as-modeled clamp position (c0 = 23.23″) the
  driven length runs 23.35–39.30″ over the full 16″ stroke, inside the
  15.52–39.75″ window — **0.45″ of top-end headroom, full stroke usable**.
  Sliding the clamp changes this; re-check after moving it.

### 3. The scale is very non-linear, with a near-cusp

10°F steps along the path:

| band | length | | band | length |
|---|---|---|---|---|
| −20..−10 | 0.79″ | | 50..60 | 12.12″ |
| −10..0 | 1.30″ | | 60..70 | 13.69″ |
| 0..10 | 2.07″ | | 70..80 | 8.04″ |
| 10..20 | 2.94″ | | 80..90 | 3.04″ |
| 20..30 | 3.92″ | | 90..100 | 8.25″ |
| 30..40 | 4.81″ | | 100..110 | **16.36″** |
| 40..50 | 5.14″ | | | |

- Spread **20.7×** (the original search rule was ≤7×, max segment ≤2.2″).
- Slowest single degree **0.073″** at −20°F, against a 0.15″ rule.
- Not monotonic: it slows at 40–50°F and again at 80–90°F.
- **Near-cusp at 43.5°F**: the indicator slows to 0.111 in/°F and the path
  swings 10°. A tight corner to engrave, and a spot where the reading barely
  moves.

None of this is a defect — the uneven scale is the point of the piece. It is
recorded so nobody assumes the search constraints still hold. They do not.

## What the DXF export gives you

Two buttons in the simulator panel. ASCII DXF (R12), units **inches**, Y flipped
to CAD convention. Curves are line segments, not splines — fit a spline in
Fusion if you want a single entity.

### Parts DXF — the five links, laid flat

One layer per part, spaced so they do not overlap:

| layer | holes | driven by |
|---|---|---|
| `CRANK` | O2, B, R (collinear) | `L2`, `rA` |
| `PLATE1` | B, C, P | `L3`, `cu`, `cv` |
| `ROCKER1` | O4, C | `L4` |
| `PLATE2` | P, D, Q | `L5`, `cu2`, `cv2` |
| `ROCKER2` | O6, D | `L6` |

Each part is drawn in its own local frame: first hole at the origin, second
along +X. Outlines are the convex hull of equal-radius circles at each hole, so
two-hole links come out as capsules and the coupler plates as rounded
triangles. Sized by the **Pivot hole ⌀** and **Link width** fields (0.375″ and
1.5″ by default).

### Points DXF — the assembly frame

| layer | contents |
|---|---|
| `SCALE_CURVE` | the path, as line segments |
| `PATH_DIVISIONS` | one mark per whole degree, cut **across** the path |
| `LABELS` | °F every 10°, and the mount names |
| `MOUNTS` | the four fixed mount holes |
| `POINTS` | snap targets at every 10° mark and every mount |

The fourth mount point is labelled `ACT_ANCHOR` in generic mode and
`ACT_CLAMP` in Joyce mode — same point, the fixed drive pivot; the label says
which bracket to build there.

Divisions are `PATHW = 1.0″` long, centered on the path. That constant lives in
`buildPoints()` in `index.html` — it is the one dimension the simulator cannot
infer, because canvas widths are in pixels. Change it there if the engraved
path width differs.

There are deliberately **no tick strokes beside the path**. The indicator is a
ring the viewer reads the temperature *through*, so anything alongside the path
would sit underneath it and be invisible.

## Still to produce

- Pivot hardware selection (bearing/bushing type, fastener sizes, retention).
- Actuator mounting-triangle detail — the anchor and rod-end brackets.
- The temp→extension calibration table for the controller. The mapping is
  linear within the excursion, with optional reversal:
  `extension = extMin + (T − Tmin)/(Tmax − Tmin) × (extMax − extMin)`.
- `.linkage2` export for David Rector's Linkage program, if wanted.

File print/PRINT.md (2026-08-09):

# 3D-printed benchtop model — serpentine (default index.html design)

Generated by `python3 tools/print3d.py`. Scale **5 mm per inch**
(1:5.1); back plate 186 × 164 mm, bar 210 mm
— all within a 210 mm bed. All parts print flat, no supports, PLA/PETG,
0.2 mm layers. Holes are 3.4 mm for M3 hardware.

## How it goes together

Every moving link rides its own plane parallel to the back plate so nothing
collides anywhere in the stroke — the level assignment is searched, then every
link pair, post shaft, sleeve, nut, head, and stub is clearance-checked over
141 poses. Posts of differing lengths stand the grounded pivots off the
plate; sleeves couple the joints across planes. Level pitch 12 mm
(4 link + 8 air); every fastener protrusion stays inside its own
air band.

| part | level (0 = closest to plate) |
|---|---|
| rocker1 | 0 |
| plate1 | 1 |
| crank | 2 |
| bar | 3 |
| rocker2 | 4 |
| plate2 | 5 |

## Screws (M3; washers column = mm of washers under the head to trim excess)

| joint | stack | grip mm | screw | washers |
|---|---|---|---|---|
| O2 | crank + post 30 + plate, nut under plate | 38.0 | M3×45 | 1.5 |
| O4 | rocker1 + post 6 + plate, nut under plate | 14.0 | M3×20 | 0.5 |
| O6 | rocker2 + post 54 + plate, nut under plate | 62.0 | M3×70 | 2.5 |
| ANCH | bar + post 42 + plate, nut under plate | 50.0 | M3×60 | 4.5 |
| B | flush head in crank + sleeve 8 + plate1, nut+washers below | 14.0 | M3×20 | 2.5 |
| C | plate1 + sleeve 8 + rocker1 | 16.0 | M3×20 | 0.5 |
| P | plate1 + sleeve 44 + plate2 | 52.0 | M3×60 | 4.5 |
| D | plate2 + sleeve 8 + rocker2 | 16.0 | M3×20 | 0.5 |
| R | flush head in crank + sleeve 8 + shuttle, nut in puck recess | 15.9 | M3×20 |  |
| Q | ring + plate2, nut+washers below | 6.5 | M3×10 |  |

Ground screws (O2/O4/O6/ANCH) drop in from the top; their nuts hide under the
plate inside the feet height. **B and R take FLAT-head (countersunk) M3** —
they sink flush into the crank's pockets (B from above, R from below), because
those two joints sit only 6.2 mm apart on
the crank arm. Everything else is button/socket head.

## Printed parts

- `backplate.stl` — the scale curve is a raised ridge on top; feet lift it so
  the under-plate nuts clear. Mount holes at O2, O4, O6 and the actuator anchor.
- `crank/plate1/rocker1/plate2/rocker2.stl` — the five links, 4 mm.
  The plates are hollow triangles on purpose: filled ones sweep over the posts
  and no collision-free stacking exists. The crank carries the two flush pockets.
- `bar.stl` — the hand drive: pivots on the anchor post; its slot ends ARE the
  excursion stops (ext 0 and 15.5″ scaled), so it cannot jam the linkage
  past the actuator ceiling (dA+rA), and its tip is trimmed to clear the P sleeve.
- `shuttle.stl` — a flat puck riding the slot, screwed into the crank's R hole;
  push it along the bar to drive the model. The M3 nut sinks into its hex recess.
- `ring.stl` — indicator at Q: read the raised path through the ring, like the sim.
- `post_*mm.stl` / `sleeve_*mm.stl` — standoffs by length: posts [6.0, 30.0, 42.0, 54.0] mm,
  sleeves [8.0, 44.0] mm. The filename is the label.

## Assembly

1. Print everything. Drop the four ground screws through their links and posts
   into the plate; nut underneath, snug but free.
2. Build in level order (table above), bottom up.
3. Couple B, C, P, D with sleeves between planes (B's flat head sinks into the
   crank top, nut below plate1).
4. Bar onto the anchor post, shuttle boss into the slot, flat-head screw up
   from under the crank at R, nut into the puck recess.
5. Ring onto Q, nut under plate2. Push the puck end to end — the ring should
   trace the raised path, both slot ends stopping inside the safe stroke.

Tuning knobs are the constants at the top of `tools/print3d.py` (clearances,
thicknesses, bed size). `assembly.stl` shows everything placed at mid-stroke.
Follow-ups not built: temperature divisions/labels on the ridge (needs a font).
// ponytail: flat extrusions only — no boolean CSG anywhere.

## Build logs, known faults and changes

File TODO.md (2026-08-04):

# TODO

Open work and known concerns. Fabrication measurements and the DXF layer
reference live in [FABRICATION.md](FABRICATION.md); design constraints and code
architecture in [CLAUDE.md](CLAUDE.md).

## Blocking fabrication

- [ ] **O2 clears the path by only 2.06″** — the rule is ≥2.5″, so it is short
      by 0.44″. Every other mount is comfortable (O6 5.28″, ACT 15.77″,
      O4 16.11″). Either move O2 or accept the clearance and record why.
      The mount-to-mount *crossing* rule was dropped on 2026-07-19; only
      clearance still applies.
- [ ] **Actuator headroom is ~0.25″ on the GENERIC actuator.** `dA+rA = 40.25″`
      stops the drive triangle closing past ~15.75″ of extension, and the
      excursion is 15.5″. Re-run `tools/analyze_geometry.py` after touching
      `dA`, `rA` or the excursion — this is the constraint most likely to be
      broken silently. **The Joyce type retires this**: at the as-modeled
      clamp position (c0=23.23″) the full 16″ stroke closes with 0.45″ to
      spare, asserted by `verify_export.py`. Decide which actuator the build
      uses and re-tune the excursion accordingly.
- [ ] **The joyce tube tail is not in the bounding box.** `buildBBox` bounds
      the path, joint traces and mounts; up to ~24.7″ of actuator body sweeps
      behind the clamp and isn't counted in the footprint readout. fitView
      DOES include it (the drawing and the drag handle stay on screen) — this
      is only about the measured w×h. Owner call on whether the envelope
      should include the actuator.

## Fabrication document

- [ ] Pivot hardware: bearing or bushing type, fastener sizes, retention.
- [ ] Actuator mounting-triangle detail — anchor and rod-end brackets. For the
      Joyce: the clamp's pivot pin and rod clevis both take Ø0.472″ (12 mm)
      pins; see the measured table in FABRICATION.md.
- [ ] `JOYCE.side` (which side of the tube the pivot ear points, +1/-1 in the
      code) is a mounting choice — confirm against the sculpture plane before
      welding the clamp mount.
- [ ] temp→extension calibration table for the controller. Mapping is linear
      within the excursion, optionally reversed:
      `ext = extMin + (T−Tmin)/(Tmax−Tmin) × (extMax−extMin)`.

## Nice to have

- [ ] `.linkage2` export — the chosen geometry as XML for David Rector's
      Linkage program (Windows, blog.rectorsquid.com). Not started.
- [ ] `PATHW = 1.0″` (engraved path width, used for the DXF division length)
      is hardcoded in `buildPoints()`. Expose it as a field if it needs tuning
      against real stock.
- [ ] The README GIF predates the bounding box and the current geometry.
- [ ] The feasibility overlay tints bad cells; a stroked boundary line
  (marching squares over the same grid) would be crisper if wanted.
      Regenerating costs another ~4.6 MB in git history, so it was left alone.

## Mobile (mobile.html, added 2026-07-31)

- [ ] **Only 6 of the 14 °F labels survive on a phone at 1×.** The thinning
      rule is honest — they genuinely overlap at that scale, and pinching in
      brings the rest back — but the owner has not seen it on real hardware
      yet. If it reads as too sparse, `LBLGAP` in `drawScale` is the knob.
- [ ] **Joint pins sit ~10px apart at the default zoom.** A fingertip covers
      several; nearest-wins picks one, and pinching to ~12× spreads them to
      ~126px. The help says so and `verify_mobile.py` asserts it. Worth
      confirming this is workable in the hand before calling it settled — the
      alternative would be a "zoom to a joint" affordance, which is more UI.
- [ ] Fine numeric entry on a phone is pinch-and-drag only. `?desktop=1`
      reaches the full slider panel on the same device; if that turns out to
      be the thing actually reached for, a numeric-entry sheet for the
      selected handle is the smallest fix.
- [ ] Untested on real iOS/Android hardware — everything so far is headless
      Chromium at a 390×844 phone viewport. The `dvh`, safe-area and
      focus-zoom work is exactly the kind that only fails on the real device.

## New scale-curve designs (SEARCH-PLAN.md) — DONE 2026-08-03

- [x] Seeded transmission-angle search from example-08/example-00 — frontier
      in REPORT.md. Owner kept two of twelve candidates: presets `shape-01`
      (13°) and `shape-02` (16°).
- [x] Reverse pipeline for the rest: drawn proposals (`propose_shapes.py`) →
      owner picked five → approximate path synthesis + ta-lift ladders →
      owner chose four off the tagged verdict sheet at their 6° criterion:
      `shape-03`…`shape-06` (7.5°/6.9°/14.0°/25.3°). Family complete at six
      per the owner. Lesson recorded in REPORT.md: present ONLY designs
      tagged buildable/not — the trade-off ladders alone confused the pick.

## Design decisions to re-confirm

- [ ] The scale is very uneven — 10°F steps run 0.79″ to 16.36″ (20.7×), and
      the slowest degree covers 0.073″. Both are well outside the original
      search constraints. Accepted as an aesthetic choice; worth one more look
      before it is cut, since it cannot be changed afterwards.
- [ ] **Near-cusp at 43.5°F**: the indicator slows to 0.111 in/°F and the path
      turns 10°. A tight corner to engrave and a spot where the reading barely
      moves.
- [ ] Owner once asked for "beginning and ending point control for actuator";
      the clarification came back "no preference". The excursion fields may
      already cover it. Confirm before building anything else.

## Settled — do not redo

These were tried and deliberately reverted or removed. The reasons are in
CLAUDE.md; listed here so they do not get "fixed" again.

- Sub-ticks at 1° — built, then removed. The path divisions say the same thing.
- White tick strokes beside the path — removed. The indicator ring covers
  anything alongside the path.
- The groove drop-shadow — deleted. It was what made the divisions appear only
  where the path climbs.
- Auto-restoring settings from localStorage on load — removed. The page always
  opens on the defaults in `index.html`; saved designs are opt-in only.
- The mount-to-mount crossing rule — dropped by the owner.
- A responsive `index.html` for mobile — the owner chose a separate
  `mobile.html` instead, with `tools/sync_core.py` holding the shared half
  identical. Don't merge them back without asking.
- Geometry sliders on `mobile.html` — deliberately removed ("rely more on
  user dragging"). All 16 are set by dragging their pin. `?desktop=1` is the
  escape hatch, and `verify_mobile.py` asserts the exact id-set difference,
  so adding one back will fail the suite on purpose.
- The drag VALIDITY GATE (built 2026-08-03, removed 2026-08-04). It blocked
  any drag that would make the design unassemblable somewhere in the range,
  sliding the handle to the wall with a binary search. The owner called the
  restriction a mistake: drags are free-form, into the red and back. What
  remains is the advisory "Drag regions" overlay (checkbox, default on).
  Don't rebuild the hard block.

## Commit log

2026-07-19 Initial commit: kinetic thermometer design simulator
    Interactive simulator for an outdoor kinetic sculpture that displays
    temperature. A linear actuator drives a bell crank into two chained
    four-bar linkages; the indicator is the stage-2 coupler point, and the
    engraved scale is the curve it traces.
    - index.html: self-contained simulator (solver, canvas render, drag
    handles, presets, persistence)
    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
2026-07-19 Add named browser saves and DXF export for Fusion
    Save now takes an optional design name, kept in a localStorage map under
    couplerThermometer.saves alongside the existing auto-restore slot. A
    dropdown loads a named design back and Delete removes one; "Clear saved"
    still only clears auto-restore.
    Two DXF exports (R12 ASCII, inches, y flipped to CAD convention), each
    offering a real Save dialog via showSaveFilePicker with an <a download>
    fallback:
    Parts DXF - the 5 fabricated links, each flat in its own local frame on
    its own layer, laid out side by side. Outlines are the
    convex hull of equal-radius circles at the holes, so 2-hole
    links come ou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
2026-07-19 Add undo, panning, 1-degree ticks; adopt tuned serpentine
    Interaction:
    - Grabbing a handle switches auto-cycle off - you can't tune against a
    moving target.
    - Undo (button + Ctrl/Cmd+Z, 60 deep) over drags, preset switches, Reset,
    and loading a saved design. A drag snapshots once on first movement, so
    grab-and-release pushes nothing. Restores the range and excursion as well
    as the geometry, since loading a design changes both. The preset label is
    re-derived from the restored geometry rather than snapshotted, because the
    dropdown has already moved by the time its change event fires.
    - Right-drag pans, as does dragging empty canvas so it works on touch;
    double-click recenters. Pa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
2026-07-19 Subdivide the path on whole degrees; drop shadow and tick strokes
    The black lines across the path were never a feature - they were a side
    effect of the drop shadow being offset in +y only. Each of the 140 sample
    segments painted its shadow over the previous segment's colour, and that
    overpaint showed as a division. Two consequences: the divisions fell on
    arbitrary sample boundaries (~0.93F apart, drifting out of step with the
    ticks), and they only appeared where the path climbs or runs sideways on
    screen. Where it descends, the shadow landed forward along the path and the
    next chunk's own colour repainted it - so there were no divisions at all
    between 60 and 80F. Confirmed by sampling render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
2026-07-19 Make the indicator a transparent ring; refresh README image and docs
    The indicator was a filled bead with a glow and a dark centre dot, which hid
    the path underneath it. It is now just the r=9 outline - same diameter, no
    fill, no centre - so the path and its divisions read straight through and
    you can count the marks the ring is sitting on. This is what the real
    sculpture's indicator will be: a ring with a hole you read the scale
    through. It no longer carries the temperature colour; the path does.
    images/index.png replaced with a current render.
    CLAUDE.md had drifted on five points, all now corrected:
    - The path and its divisions, including why the divisions must stay
    explicit rather tha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
2026-07-19 Replace the README still with a per-degree animated GIF
    images/index.png -> images/index.gif. 860x526, 260 frames at 30ms, looping,
    7.8s a cycle.
    One frame per whole degree, which is the point: every degree gets equal
    TIME, so the indicator visibly crawls through the compressed cold end and
    races through 60-110F. The animation now demonstrates the non-linear scale
    rather than just showing the linkage move. Added a line under the image
    saying so, otherwise the uneven pacing reads as a stuttery capture.
    The loop is a ping-pong with no jump at the seam. Only the 131 ascending
    frames are rendered; the descending half reuses them reversed.
    Note this puts a 4.6 MB binary permanently in history.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
2026-07-19 Add an envelope bounding box with a Display checkbox
    A dashed rectangle around the whole design, labelled with its overall width
    and height in inches, to give a sense of the piece's real scale. 33.6 x 19.3
    for the current serpentine.
    It bounds the path plus the four fixed mounts - the same definition already
    used for "37 x 19" in CLAUDE.md. It does NOT include the swept linkage, so
    the inner curves can visibly extend past it.
    Two details that matter:
    - buildBBox runs BEFORE fitView in rebuildPath. fitView deliberately
    early-returns while a mount is being dragged, to hold the view still;
    computing the box after it would freeze the numbers mid-drag. Verified it
    reads 33.6 -> 37.9 live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
2026-07-19 New tuned serpentine; never auto-load localStorage
    Owner's third hand-tuned geometry, from a __ct.dump() capture. 82.5" of
    scale, up from 58". Assembles across the full 0-15.5" excursion.
    Measured with tools/analyze_geometry.py. Better and worse than what it
    replaces, recorded honestly:
    - O6 mount clearance fixed: 0.97" -> 5.28". O2 is now the offender at 2.06"
    against the >=2.5" rule, and three mount pairs still cross the path, all
    of them involving the actuator anchor. Still a build blocker.
    - Actuator ceiling eased slightly: dA+rA is 40.25 rather than 40.15, so the
    drive triangle closes to ~15.75" instead of ~15.65".
    - Motion is less even: 10F steps run 0.79" to 16.36" (20.7x, was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
2026-07-19 Link the live demo in the README
    GitHub Pages is now enabled on this repo, serving main at the root, so
    index.html is live at:
    https://holla2040.github.io/kineticThermometer/
    Linked from the header and from the index.html entry in the Files list.
    Pages builds straight off main, so a push updates the demo.
    Verified by driving the hosted page: it loads with no errors and comes up
    on the current defaults (rot 110, inner curves off, bounding box off,
    82" of scale).
2026-07-19 Drop the mount-crossing rule; make the DXF match the simulator
    Two of the outstanding issues.
    1. The mount-to-mount crossing requirement is dropped at the owner's
    request. Mounts may now sit on either side of the path. Removed from
    every place it was encoded: the seg_int test in search_geometry.py, the
    crossings report in analyze_geometry.py, fabrication rule 3 in CLAUDE.md,
    and the PRESETS comment in index.html. search_geometry's
    mounts_same_side is renamed mounts_ok - with the crossing test gone it
    no longer checks anything about sides, and a name asserting a property it
    stopped enforcing would mislead.
    The >=2.5" clearance rule stays, and the serpentine still fai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
2026-07-19 Wheel zoom, screen-aligned swept-envelope box, TODO and FABRICATION docs
    Mouse wheel zoom. Wheel FORWARD zooms in, cursor-anchored so the point under
    the pointer stays put (holds within 0.3px). Clamped 0.15-12x; double-click
    resets zoom as well as pan. Two knock-ons: fitView now centres using the
    ZOOMED scale, or a refit would jump the view whenever zoom != 1, and the
    drawn actuator body scales with it.
    The bounding box is now square to the screen at any view angle. It is
    measured in ROTATED space and drawn with a new TXr() - the transform split
    into TXr(alreadyRotatedPoint) and TX() = TXr(rotPt()) - so it is not rotated
    twice. Consequence, and it reverses an earlier invariant: its w/h are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
2026-07-19 Add help dialog and dimension overlay; drop Show mechanism
    Help. A "?" in the panel header opens a one-page reference. It is a native
    <dialog> opened with showModal(), so Escape and the dimmed backdrop come for
    free; a click landing on the dialog element itself IS the backdrop, so that
    closes too, while clicks inside do not. There is also an x, because on touch
    there is no Escape key. Space and Ctrl+Z were leaking through the modal into
    the simulator behind it - the global keydown handler does not know about
    modality - so it now returns early while help is open.
    Dimensions checkbox. Labels every link, all three edges of both coupler
    plates, the live actuator length, and each mount's x,y. Ev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
2026-08-01 Add a portrait mobile build; share one core between the two pages
    mobile.html is the simulator laid out for a phone held upright. The owner chose
    a separate file over a responsive index.html, and full editing parity MINUS the
    sliders - "rely more on user dragging, remove the placement and length sliders".
    All 16 geometry sliders are gone. Every one already had a canvas handle, so the
    10 handles are now the only way to set them, and verify_mobile.py asserts the
    id-set difference against index.html exactly - a forgotten control and an
    over-eager deletion both fail. What stays is everything with no drag
    equivalent: excursion, the stage flips, rotation, the temperature range,
    display toggles, p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
2026-08-01 Full-page Reset, drag winds the sweep up, one-row mobile toolbar
    Reset now means the page as it first opened: geometry back to the preset,
    every cfg value back to CFGDEFAULTS, and rotation/zoom/pan squared up. UNDOCFG
    widened to all of cfg except temp and demo, so one undo puts the lot back.
    On mobile a drag no longer pauses the sweep — it winds it up to DRAGSPEED (1x)
    so the whole excursion of the change plays out under your finger, and every
    exit from a drag restores the speed. A tap alone does nothing: the 30px touch
    radius over ~10px pin spacing means almost any poke lands on a handle.
    Toolbar is one row across the top — ? at the far left, then play/undo/reset/fit
    at the right, wit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
2026-08-03 Editable retracted length and stroke for the generic actuator
    New Retracted/Stroke fields in the Actuator drive section of both pages
    (ids shared, so the mobile parity check is untouched). The stroke bounds
    the excursion fields live via clampExcursion(); editing either dimension
    is a geometry edit and flips the preset to custom. Section summary and
    help text stop hardcoding 24-42in / 18in. syncActUI() keeps the fields,
    row visibility and excursion max attributes in step, null-guarded the
    same way the slider wiring is.
2026-08-03 Joyce QS11940 actuator type: selector, clamp-position field, kinematics
    Actuator type select on both pages: generic pin-to-pin, or the Joyce
    QS11940 whose rear mount is a clamp sliding on the tube with its pivot
    pin 2.378" off the centerline. Driven length sqrt((c0+ext)^2+off^2);
    stroke fixed at 16" and it re-clamps the excursion on switch. Clamp
    position field 3.48-24.66" (measured travel). Still drawn generic-style;
    the offset-clamp render is the next commit.
    Verified end to end: python recomputes pose().R from raw geo to 1e-9 at
    three temperatures; named-save round-trip; pre-actuator-types saves load
    as the original generic; preset switch resets the type and undo restores
    it. And the pay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
2026-08-03 Draw the Joyce actuator at real scale; label its DXF mount ACT_CLAMP
    actGeom() gives the joyce tube frame: the tube runs parallel to
    pivot->R, offset 2.378", so the render shows what the hardware does -
    a fixed clamp the tube slides through, rod extending to the crank pin.
    Tube Ø2 and rod Ø1.378 stroked at drawing scale (with px floors), motor
    pod on the rear 3.78", clamp glyph straddling the tube at the pivot
    foot, bracket out to the hatched mount. Hover hits the whole tube.
    Points DXF names the 4th mount ACT_CLAMP in joyce mode; same 4 mounts,
    same datum coordinates. Tests assert the frame invariants (R on the
    axis, pivot exactly off by JOYCE.off, tube at body length) and both
    DXF labels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
2026-08-03 Drag the clamp body to slide it along a fixed actuator
    Three drive drags now, matching the physical moves: the tube TAIL slides
    the tube through a fixed clamp (aClamp only, as before); the CLAMP BODY
    slides the clamp along a fixed tube - aClamp and the pivot mount move
    together (A' = A + slide*u) so the tube and the whole pose at the current
    temperature stay exactly put; the PIVOT PIN still moves the whole drive
    with the clamp position untouched. The old 'clamp' tail handle is renamed
    'tail'; 'clamp' now grabs the clamp itself, with a hover target on the
    glyph and the three affected values in the drag tip.
    Tests: clamp-body drag leaves R fixed to 1e-9 with the pivot displaced
    exactly slide*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
2026-08-03 Persist the actuator choice across reloads
    geo.actT is stored under couplerThermometer.actT and restored at init -
    the one deliberate exception to "the page opens on defaults", because
    which actuator you own is hardware, not a design edit. persistActT()
    compare-and-writes from rebuildPath(), so the select, preset switches,
    undo, Reset and design loads are all covered by one hook. Geometry,
    clamp position included, still opens on the preset defaults; tests
    assert both halves and that switching back to generic persists too.
    Also corrects CLAUDE.md's stale couplerThermometer.v2 auto-restore
    paragraph.
2026-08-03 Click the red range warning to reset the design
    A drag that breaks the linkage turns the range box red; clicking (or
    tapping, in the mobile sheet - shared-core wiring) that red box now runs
    the same full resetAll as the Reset button, and the reset is undoable.
    The message says 'Click here to reset', the cursor turns pointer, and
    the green box is inert. Tested on both pages, including the undo path
    and green-box no-op.
2026-08-03 Bell crank becomes a real two-arm plate: attach the actuator anywhere
    New geo.bAng (degrees, default 0 = the old collinear behavior, so
    presets and old saves are untouched): the coupler pin B rides bAng off
    the actuator arm. Dragging B now places it anywhere on the crank plate
    - it lands exactly under the cursor - and dragging R slides the
    actuator attachment radially while bAng auto-compensates so B and the
    whole downstream chain hold perfectly still. The actuator connection
    point is fully independent of the coupler joint. Crank draws as two
    arms (a V when bent); the CRANK DXF part places R off the B-arm with
    the same flipped-y chirality as the coupler plates, verified against
    the world pos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
2026-08-03 Arrow keys: Up/Down step the actuator extension 0.1", Left/Right rotate
    Desktop keyboard, alongside Space and Ctrl+Z: Up/Down nudge the reading
    by exactly 0.1" of actuator extension (mapped through the temp scale,
    reverse-scale aware, clamped to the excursion; stepping stops the
    sweep like the reading slider does) and Left/Right turn the view 10
    degrees through the rotate slider's own handler. Arrows only fire when
    no control has focus, so sliders and fields keep their native keys.
    Hint bar documents them.
2026-08-03 R slides along the crank arm; the actuator translates with it
    Reverts the two-arm bell crank (bAng) from the previous commit - on
    screen it read as the linkage splitting into a second four-bar and it
    broke far too easily (owner screenshot). R and B are collinear again,
    now recorded as by-design in CLAUDE.md.
    In its place, the R drag becomes the connection-slide the owner asked
    for: the cursor projects onto the arm's axis (range widened to 2-30",
    so past B or in close to O2, never off the line) and the anchor mount
    translates with the end point - pin-to-pin length and the whole pose
    stay frozen while you choose where on the arm the actuator connects.
    Reshaping the drive triangle against a fi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
2026-08-03 Drags can't break the design: validity gate + no-go overlay on grab
    A drag may never take a design that assembles across its full excursion
    (pathValid, the red warning) into one that doesn't. applyDrag splits into
    mutateDrag (pure mutation, returns touched keys) plus a wrapper that checks
    rangeValid() — the same 141 samples as rebuildPath — and binary-searches a
    blocked move to the wall, so the handle slides to the edge instead of
    jumping past it. A design that is already red drags freely: that is how
    you heal one. O2 is gated too (it is not a pure translation), but being
    delta-based gets no overlay.
    Grabbing a handle tints the unreachable region: a screen-space grid is
    scanned in 5ms r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
2026-08-03 Remove the drag validity gate; put the region overlay behind a checkbox
    Owner reversed both 2026-08-03 decisions: constraining drags to the good
    region was a mistake, and the overlay should be optional. Drags are
    free-form again — into the red and back, with the no-go tint and the red
    range box doing the informing instead of a hard block.
    applyDrag is back to mutate + UI sync (the mutateDrag split stays; the
    overlay depends on it). New "Drag regions" checkbox in both pages' Display
    sections (cfg.region, default on) switches the overlay; startDragRegion
    respects it. rangeValid and dropNoopUndo stay in the core.
    Tests: tail-yank and R-slide assertions restored to their originals (pins
    at c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
2026-08-03 Explain dead centre: mark it in the menu, show it live, document it
    The eleven example presets all pass within 6 degrees of a dead-centre
    singularity, where the two circle intersections that locate a joint merge into
    one. Two things go wrong there: the indicator's speed off a given actuator step
    is unbounded, and the linkage no longer has a branch to stay on, so it can come
    off on the mirror assembly and read wrong until something knocks it back.
    Three changes make that visible instead of a trap.
    Each example preset carries a * in the dropdown. C and D turn red whenever their
    own transmission angle drops below 6 degrees, and the inner curve for that pin
    turns red over the whole stretch of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
2026-08-03 Show the eleven examples in the README; render the sheet from the presets
    The contact sheet was built from designs.json, a saved snapshot of the search
    output -- which is how it drifted: it still showed all fifteen candidates under
    their search names, including the four that were rejected, at the full-stroke
    lengths rather than the ones the page actually draws.
    render_designs.py --presets reads the preset list out of index.html and drives
    the real dropdown instead, asserting each one assembles and draws all 130 chunks
    before it shoots. It cannot show a curve the menu does not produce. Output is
    byte-identical run to run, so a regenerated sheet that differs means the presets
    moved.
    The shee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
2026-08-09 Add 3D-print pipeline for the serpentine benchtop model (3DFab levels)
    Extend the flat default design into 3D for a 1:5.1 printed model on a
    220mm bed: posts of differing lengths stand the fixed mounts off a back
    plate, each link rides its own parallel plane, sleeves couple the joints
    across planes, and a slotted bar + shuttle puck reproduces the actuator
    constraint with the stroke stops built into the slot ends.
    tools/print3d.py searches the level assignment (rocker1 lowest through
    plate2 on top; hollow triangle plates and the trimmed bar tip are
    load-bearing) and clearance-checks links, posts, sleeves, and every
    fastener protrusion over all 141 poses. print/ carries the 16 STLs,
    PRINT.md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
    [assembly.stl, backplate.stl, bar.stl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]
2026-08-09 Report the 3dfab-level work: print pipeline and the Fusion rebuild
    Appends a section to REPORT.md covering both halves of this branch: the
    print3d.py generator (searched level assignment, the four load-bearing
    results, what print/ contains) and the native Fusion 360 assembly built
    from print/fusion-data.json.
    Records what the Fusion rebuild established, so it is not re-derived: a
    slider joint shuttle-bar silently locks the solver and only a pin-slot
    drives, which costs the puck's idle spin (2 DOF, one of them real); large
    drive steps flip the plate2/rocker2 loop to its other branch and 0.4mm
    steps do not; the scale ridge must be a union of capsules because the Q
    path self-crosses. Verificat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
2026-08-09 Respace shape-01's B and R pivots so the crank is fabricable
    As shipped, shape-01 put B and R only |rA-L2| = 0.1286" apart on the
    crank arm. That is a ratio, not a resolution problem: at full size with
    3/8" pivots the two holes' centres sit closer together than one hole
    diameter, so they merge into a single slot. Scaling does not help - a
    3/8" pin with a pin-diameter of steel between the holes would need the
    piece built ~5.8x full size, about 17 ft.
    rA/L2 go 11.2952/11.4238 -> 11.1125/11.8625, opening the gap to exactly
    0.750" = one pin diameter between the holes at 3/8", and clearing 1/4"
    with margin. The pair was picked by searching 7381 candidates with the
    gap pinned at >= 0.75 and ranki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
2026-08-09 Respace shape-01 to 24.0mm on the actuator's own metric hardware
    Supersedes the 0.750" spacing committed in e88ec41. Two things came out of
    measuring the owner's Joyce QS11940 model that make 0.750" the wrong number.
    First, the rod end is natively METRIC and the imperial figures in
    FABRICATION.md are conversions: pin 12.000, tang eye 34.000, tang thickness
    14.000, tang width 26.000, rod 35.000, pin 51.000 ahead of the tube front,
    tang-to-rod step 27.000, all mm and all exact. Only the tube is imperial
    (50.80 = 2.000"). R therefore takes a 12mm pin because the part says so.
    Second, the crank runs on ONE side of the tang rather than straddling it,
    so both fasteners sit on the crank face and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
2026-08-09 Add the export->bench-data pipeline; report the full-scale Fusion build
    tools/export_trace.py drives the page and exports a TRACE: geo, cfg and the
    joint positions the page itself computed over 141 poses, plus lenOf/stroke.
    Downstream then transcribes rather than re-derives, which matters because
    print3d.py's solve() hardwires the generic 24..39.5in drive length instead of
    calling drive_lengths(), so it builds the wrong mechanism for any joyce design.
    serpentine is generic, which is why that never showed.
    tools/benchmodel.py consumes a trace and re-implements the level search,
    fastener policy and hardware verification with NO dependencies - every
    collision test in print3d is capsule-vs-caps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
2026-08-10 Report making the full-scale assembly articulate
    kineticThermometer (Fusion, cloud v29) now has 29 joints and drives: push the
    actuator and the mechanism follows with the rod staying in its tube.
    |R-ANCH| matches sqrt((aClamp+e)^2 + off^2) to 0.0001mm across the whole
    393.7mm stroke, and Q lands on its expected point to 0.230mm median /
    1.116mm worst over all 141 sample extensions.
    The actuator is a LINKED reference now, not the SAT copy. That copy was the
    root of a wasted afternoon: SAT flattened the owner's three components into
    five loose bodies and discarded the joints, so everything after it was
    rebuilding badly what the source already had. addByInsert had thrown
    InternalValidationErro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
2026-08-21 Start the controller design: docs home, ESP32 DevKitC references
    controller/README.md is the ongoing controller-design discussion: TMP117
    as the temperature sensor, ESP32 DevKitC as the MCU, and the motor-driver
    shortlist (DRV8245 / VNH7070 / MP6615) summarized from the owner's ChatGPT
    sourcing thread. controller/docs/ holds the DevKitC schematics and pinouts.
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
